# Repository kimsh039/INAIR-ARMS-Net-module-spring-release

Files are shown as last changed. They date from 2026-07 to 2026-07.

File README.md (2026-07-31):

<<<<<<< HEAD
# Net Module Spring Release Mechanism

드론 날개를 잠금 상태에서 스프링 힘으로 전개하고, 연동 래치를 해제하는 `net_module` 메커니즘의 Fusion 360 설계 파일과 MATLAB/Simulink 동역학 검증 자료를 정리한 프로젝트다.

## 결론

현재 형상과 추정 질량을 기준으로 한 1차 권장 사양은 다음과 같다.

| 항목 | 권장값 |
|---|---:|
| 스프링 종류 | 인장 스프링 |
| 스프링 상수 | **0.25 N/mm 전후** |
| 자유 길이(후크 포함) | **약 31 mm** |
| 초기 장력 | **약 1.5 N** |
| 잠금 상태 장착점 거리 | 54.339 mm |
| 전개 상태 장착점 거리 | 약 35.6~36.83 mm |
| 요구 안전 신장량 | 최소 24 mm 이상 |
| 잠금 상태 장력 | 약 7.33 N |
| 예상 90% 전개 시간 | 약 101.5 ms |
| 예상 최대 캠 각속도 | 약 1,346 deg/s |
| 권장 외경/선경 시작 범위 | 외경 6~8 mm / 선경 0.6~0.8 mm |

구매 또는 제작 시에는 `k ≈ 0.25 N/mm`, 자유 길이 약 31 mm, 최대 사용 길이 54.34 mm에서 반복 사용 가능한 제품을 우선 검토한다. 후크가 진동으로 빠지지 않도록 폐쇄형 루프 또는 별도 이탈 방지 구조를 사용하는 것이 좋다.

## 시뮬레이션 결과

### 스프링 상수 비교

| 스프링 상수 | 90% 전개 시간 | 최대 캠 각속도 | 잠금 장력 |
|---:|---:|---:|---:|
| **0.25 N/mm** | **101.45 ms** | **1,345.6 deg/s** | **7.33 N** |
| 0.30 N/mm | 96.22 ms | 1,421.6 deg/s | 8.50 N |
| 0.35 N/mm | 91.75 ms | 1,494.1 deg/s | 9.67 N |

0.35 N/mm는 0.25 N/mm보다 약 9.7 ms 빠르지만 잠금 장력이 약 32% 증가한다. 3D 프린트 래치의 충격, 마모, 체결 하중을 고려하면 0.25 N/mm가 가장 균형 잡힌 시작점이다.

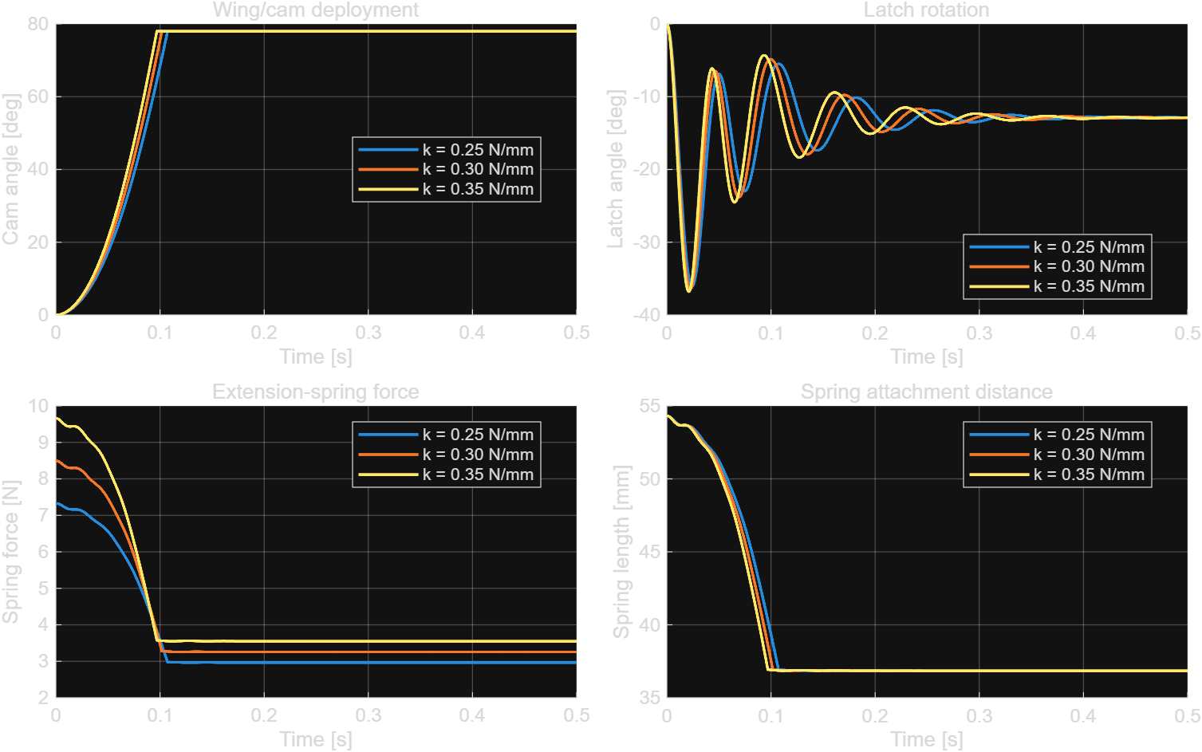
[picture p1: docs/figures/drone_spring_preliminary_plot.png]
MATLAB spring sweep


### MATLAB과 Simulink 교차 검증

| 항목 | MATLAB | Simulink | 차이 |
|---|---:|---:|---:|
| 90% 전개 시간 | 101.45 ms | 101.53 ms | 0.08 ms |
| 최대 캠 각속도 | 1,345.6 deg/s | 1,346.0 deg/s | 0.4 deg/s |
| 최대 스프링 장력 | 7.33 N | 7.33 N | 사실상 일치 |

Simulink 최종 상태는 캠 각도 78.10 deg, 래치 각도 -12.88 deg, 최소 스프링 길이 36.83 mm로 계산됐다.

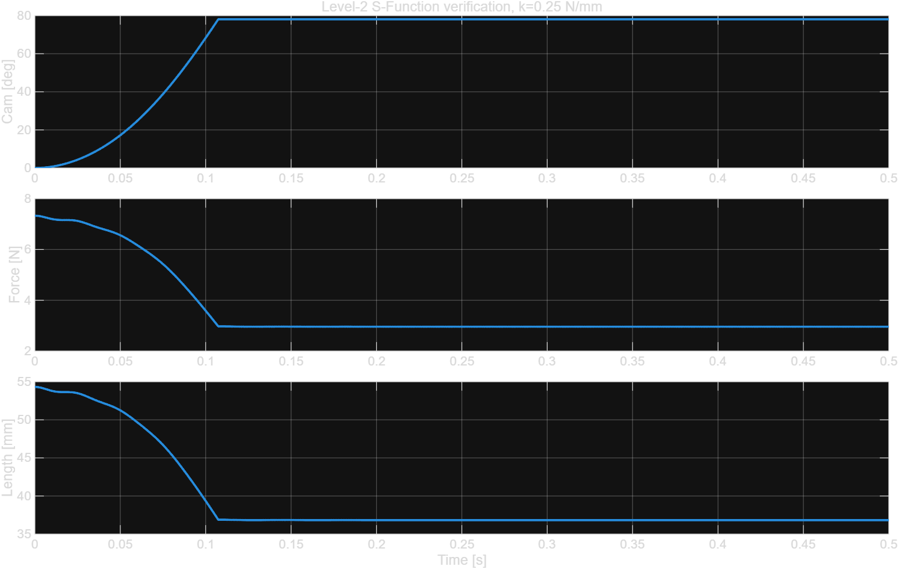
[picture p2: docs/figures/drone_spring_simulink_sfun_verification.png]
Simulink verification


## Fusion 360 측정값

- 잠금 상태 스프링 장착점 중심 거리: 54.339 mm
- 전개 상태 거리: 약 35.6 mm(화면 형상 추정), Simulink 최소 거리 36.83 mm
- 큰 캠 장착점 모멘트암: 약 14.7 mm
- 래치 장착점 모멘트암: 약 6.3 mm
- PLA 100% 솔리드 가정 출력 부품 질량: 약 42.6 g
- RS2205 2300KV 모터 질량: 제조사 정보가 없어 30 g으로 가정

PLA 질량은 Fusion 솔리드 체적에 밀도 1.24 g/cm³를 적용한 값이다. 실제 인필, 벽 수, 볼트와 배선이 반영되지 않았으므로 출력 후 실측 질량과 무게중심으로 갱신해야 한다.

## 모델 구성

검증된 Simulink 모델은 2자유도 평면 모델이며 다음 효과를 포함한다.

- 캠/날개 회전 관성
- 래치 회전 관성
- 중력 토크
- 회전 감쇠(마찰 근사)
- 장착점 형상에 따른 인장 스프링 힘과 토크
- 캠 및 래치 회전 제한

`simulation/simulink/drone_spring_2dof_sfun.slx`가 검증된 모델이다. 동역학은 `drone_spring_sfun.m`에 구현돼 있다.

## 실행 방법

필요 환경:

- MATLAB R2025b 또는 호환 버전
- Simulink

MATLAB 파라미터 스윕:

```matlab
run('simulation/matlab/drone_spring_preliminary_sim.m')
```

Simulink 모델 재생성 및 검증:

```matlab
run('simulation/simulink/build_drone_spring_simulink_sfun.m')
```

저장된 Simulink 모델을 직접 열려면:

```matlab
open_system('simulation/simulink/drone_spring_2dof_sfun.slx')
```

모델의 `Spring rate N_per_mm` 블록 값을 변경하면 다른 스프링 상수를 시험할 수 있다.

## 프로젝트 구조

```text
cad/fusion360/                 Fusion 360 부품 모델(.f3d)
simulation/matlab/             MATLAB 파라미터 스윕 및 결과
simulation/simulink/           검증된 Simulink/S-Function 모델 및 결과
docs/figures/                  결과 그래프
```

## 한계와 다음 검증

현재 결과는 스프링 1차 선정용이다. 최종 선정 전 다음 값을 실측해 모델을 갱신해야 한다.

1. 출력 완료된 날개/캠/래치의 실제 질량과 무게중심
2. 래치가 풀릴 때 필요한 실제 힘 또는 토크
3. 회전축 마찰과 조립 공차
4. 스프링 제조사의 초기 장력 및 허용 최대 신장량
5. 최소 100회 반복 전개 시험 후 PLA 마모와 균열 여부

특히 프로펠러가 회전 중인 상태의 전개는 현재 모델 범위 밖이다. 비행 중 전개를 계획한다면 공력 하중, 모터 자이로 효과, 충격 하중을 별도로 검토해야 한다.
=======
# net-module-spring-release
>>>>>>> 4ec0f1f86857df83d7678cfb59a179a8000f56a4

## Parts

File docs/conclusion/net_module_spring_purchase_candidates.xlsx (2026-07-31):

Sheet: 구매 후보
Net Module 기성 인장 스프링 구매 후보
주문제작 제외 · 2026-07-31 조사 · 실제 구매 전 판매처 재고와 최신 데이터시트 확인 필요
순위 | 제조사/형번 | 재질 | 자유장 (mm) | 외경 (mm) | 선경 (mm) | 스프링 상수 (N/mm) | 초기 장력 (N) | 최대 신장 길이 (mm) | 잠금 시 예상 장력 (N) | 목표 대비 차이 (N) | 신장 여유 (mm) | 판정 | 구매/제품 링크
1 | Lee Spring LEM045B 06 S | 302 스테인리스 | 25.00 | 4.50 | 0.45 | 0.17 | 0.95 | 62.33 | 5.82 | -1.51 | 7.99 | 추천 | https://www.leespring.com/extension-springs
2 | Lee Spring LEM045B 05 S | 302 스테인리스 | 23.00 | 4.50 | 0.45 | 0.19 | 1.07 | 56.29 | 6.93 | -0.40 | 1.95 | 정적 비교시험 | https://www.leespring.com/extension-springs
3 | RS PRO 821-475 | 스테인리스 | 30.40 | 6.00 | 0.55 | 0.12 | 7.90 | 86.60 | 10.77 | 3.44 | 32.26 | 재시뮬레이션 필요 | https://kr.rs-online.com/web/p/extension-springs/0821475
4 | RS PRO 751-742 | 피아노선 강철 | 30.40 | 6.00 | 0.55 | 0.15 | 9.50 | 86.60 | 13.09 | 5.76 | 32.26 | 재시뮬레이션 필요 | https://kr.rs-online.com/web/p/extension-springs/0751742
권장 결론
1순위 LEM045B 06 S: 잠금 장력은 목표보다 낮지만 최대 신장 여유가 약 8 mm라 프로토타입에 가장 안전함.
2순위 LEM045B 05 S: 목표 장력에 가장 가깝지만 최대 신장 여유가 약 2 mm뿐이므로 정적 비교시험용으로 제한함.
RS PRO 제품은 국내 구매가 쉽지만 초기 장력이 높아 기존 모델보다 충격과 전개속도가 커질 수 있으므로 값 변경 후 재시뮬레이션이 필요함.

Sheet: 설계 기준
Net Module 인장 스프링 설계 기준
항목 | 기준값 | 단위 | 설명
잠금 상태 장착거리 | 54.339 | mm | Fusion 360 측정값
전개 상태 장착거리(최소) | 35.600 | mm | 형상 추정값
전개 상태 장착거리(시뮬레이션) | 36.830 | mm | Simulink 최소 길이
목표 스프링 상수 | 0.250 | N/mm | 기존 2-DOF 시뮬레이션 기준
목표 자유장 | 31.000 | mm | 후크 포함
목표 초기 장력 | 1.500 | N | 기존 시뮬레이션 기준
목표 잠금 장력 | 7.330 | N | 기존 시뮬레이션 결과
권장 최소 최대신장길이 | 59.339 | mm | 잠금거리에서 5 mm 여유 적용
권장 외경 | 6.000 | mm 이상 | 초기 권장 범위 6~8 mm
계산식 | 값 | 단위 | 비고
잠금 상태 변위 | 23.339 | mm | 잠금거리-자유장
목표 모델 잠금 장력 | 7.335 | N | 초기장력+k×변위

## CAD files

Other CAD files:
cad/fusion360/fixture1.f3d
cad/fusion360/fixture2.f3d
cad/fusion360/motor_case.f3d
cad/fusion360/wings.f3d

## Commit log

2026-07-31 Add net module spring mechanism project
    [fixture1.f3d, fixture2.f3d, motor_case.f3d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]
2026-07-31 add docs
    [net_module_spring_purchase_candidates.xlsx]
